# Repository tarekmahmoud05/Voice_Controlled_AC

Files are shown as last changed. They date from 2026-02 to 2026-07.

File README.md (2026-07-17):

# 🚗 Voice-Controlled Automotive Cabin Air Management System

An embedded systems project that automates rear-cabin climate control in vehicles, using dual temperature sensing, PWM-driven fan/hood logic, a custom motor driver shield PCB, and a Python voice-recognition interface for hands-free operation.

Built as part of the **Embedded Systems** and **Manufacturing of Electronic Components** modules — Electrical and Electronics Engineering, Coventry University.

---

## 📌 Table of Contents

- [Overview](#-overview)
- [Problem Statement](#-problem-statement)
- [System Architecture](#-system-architecture)
- [Hardware](#-hardware)
- [Control Logic](#-control-logic)
- [Voice Recognition Interface](#-voice-recognition-interface)
- [Repository Structure](#-repository-structure)
- [Getting Started](#-getting-started)
- [Testing](#-testing)
- [Results](#-results)
- [Future Work](#-future-work)
- [Team](#-team)
- [References](#-references)

---

## 🔍 Overview

Solar radiation through the rear windshield creates a "greenhouse effect" that conventional front-vent HVAC systems can't reach, with rear-cabin temperatures documented to exceed ambient by up to 47°C under direct sun. This forces manual driver adjustments mid-drive — a known distraction risk — and increases compressor load, raising fuel consumption by roughly 8%.

This project tackles that with a **roof-mounted ventilation system** built around an **AVR ATmega328P**, which autonomously switches between **intake (Fan Mode)** and **exhaust (Hood Mode)** based on real-time temperature deltas between the cabin and the outside air. A voice-controlled desktop app lets the driver set a target temperature hands-free, and a custom-fabricated PCB drives the motor.

## ❗ Problem Statement

- Rear cabin glazing causes thermal stratification untouched by standard HVAC vents
- Manual rear-climate adjustment while driving is a documented distraction hazard
- Compensating compressor load increases fuel consumption

## 🏗️ System Architecture

System Architecture Diagram

The firmware is organized into modular driver layers (ADC, DIO, PWM, UART, LCD, Button, String utilities), each with its own `.ino`/`.h` pair, integrated in a top-level main file. Full module breakdown, pin mapping, and control-flow diagrams are in [Project Design/CW3_project_design.md](Project%20Design/CW3%20project%20design.md)

## 🔧 Hardware

| Component | Function |
|---|---|
| ATmega328P (AVR) | Processes control logic, ADC inputs, and PWM output for the fan |
| Dual LM35 Temperature Sensors | Monitor cabin (`inTemp`) and ambient (`outTemp`) temperature |
| DC Fan | Roof-mounted intake/exhaust airflow |
| 16x2 LCD Display | Real-time temperature and system status |
| Push Button | Manual Start/Stop toggle and target-temperature trigger |
| L293D IC | Dual H-Bridge for bidirectional motor control |
| L7805 CV | 5V voltage regulator for stable logic power |
| Custom Motor Driver Shield (PCB) | In-house designed, milled, and soldered 2-layer shield carrying the L293D |
| Resistors/Capacitors | UART pull-ups and decoupling |

### Custom Motor Driver Shield (PCB)

Designed and fabricated as part of the Manufacturing of Electronic Components module:

1. **Circuit Design** — Schematic design of the motor driver shield
2. **Layout Design** — 2-layer PCB layout in Altium
3. **File Conversion** — G-code generation from Altium Gerber data
4. **Surface Mapping** — Auto-leveling the FR4 board for uniform milling depth
5. **Isolation Routing** — CNC milling of copper boundaries with a V-bit
6. **Drilling** — CNC drilling for through-hole component leads
7. **Post-Processing** — Deburring, cleaning, solder mask application
8. **Soldering** — Manual soldering with multi-point continuity validation

PCB schematics, layout files, and Gerber/G-code outputs are in [`pcb/`](pcb).

## 🧠 Control Logic

**Pin Mapping**

| Component | Pin | Type | Function |
|---|---|---|---|
| Internal Temp Sensor | PC5 | Analog In | Cabin temperature (`inTemp`) |
| External Temp Sensor | PC0 | Analog In | Ambient temperature (`outTemp`) |
| Control Button | PB4 | Digital In | Start/Stop toggle, triggers UART command |
| Motor Direction 1 | PD2 | Digital Out | Direction control (w/ PD3) |
| Motor Direction 2 | PD3 | Digital Out | Direction control (w/ PD2) |
| Motor Speed (PWM) | PB2 (OC1B) | PWM Out | Duty cycle 0–255 |
| LCD Data (D4–D7) | PD4–PD7 | Digital Out | 4-bit LCD data bus |
| LCD Enable | PB1 | Digital Out | LCD enable signal |
| LCD Register Select | PB0 | Digital Out | LCD command/data select |

**Fan/Hood decision logic:**
Fan Hood Decision Logic

Speed is mapped from the temperature difference onto an 8-bit PWM duty cycle (165–255 range, set by Timer 1 in Fast PWM Mode 14), generated via `OCR1B`. Direction is set through PD2/PD3, and motor commands are wrapped in `fan()`, `hood()`, and `stop()` helper functions on top of low-level `DC_Start`/`DC_Stop` calls.

Full firmware control flow, initialization routines, and the UART status-string framing are documented in [Project Design/CW3_project_design.md](Project%20Design/CW3%20project%20design.md)

## 🎙️ Voice Recognition Interface

A Python desktop application provides hands-free target-temperature control:

1. **Audio Capture** — PyAudio with ambient noise filtering
2. **Speech Processing** — Speech-to-text via the Google Speech Recognition API
3. **Command Parsing** — Keyword filtering to extract the numeric setpoint
4. **UART Bridge** — Sends the validated value to the ATmega328P at 9600 bps
5. **GUI Feedback** — Real-time system status and target temperature via TTKBootstrap

**Workflow:** press the button to start recording → speak the desired temperature → press the button again to stop recording and send it to the MCU.

## 📁 Repository Structure

Repository Structure Tree

## 🚀 Getting Started

### Hardware Requirements
- Arduino UNO / ATmega328P
- Dual LM35 temperature sensors
- L293D motor driver IC (on the custom shield, or a breakout)
- DC fan
- 16x2 LCD (4-bit mode)
- Push button
- L7805 voltage regulator
- USB cable for UART/serial connection

### Firmware Setup
1. Open `firmware/voice_Controlled_AC.ino` in the Arduino IDE
2. Connect components according to the [pin mapping](#-control-logic) above
3. Select board: **Arduino UNO**
4. Upload the sketch

## ✅ Testing

The `tests/` directory contains automated and semi-automated Python test scripts used to validate:
- ADC temperature readings against known reference values
- Serial communication / UART protocol framing
- Fan/Hood decision logic across the cabin/ambient temperature matrix
- Voice command parsing accuracy

Demonstration videos of the full system in operation are available in same directory.

## 📊 Results

Experimental testing showed the system reliably reduces thermal stagnation in the rear cabin and switches correctly between intake and exhaust modes according to the temperature differential logic, while the voice interface reduced the need for manual driver interaction with the climate controls.

## 🔮 Future Work

- **Sensor Fusion** — Add humidity and CO₂ sensors for air quality management and glass defogging, beyond just temperature
- **Wireless Connectivity** — Replace wired UART with Bluetooth/Wi-Fi for a fully wireless smartphone/PC-to-vehicle link
- **ML-Based Optimization** — Lightweight model to predict user temperature preferences from historical data and outdoor weather conditions

## Mady by

**Eng** Tarek Mahmoud Younes,
Student at **Coventry University**,
Specialized in **Electrical and Electronics Engineering**

**Supervised by:** Dr. Mostafa Rabie, Eng. Medhat Toubar
**School of Engineering — Electrical and Electronics Engineering, Coventry University**

## 📚 References

1. Alkhalaf, A., et al. (2021). *Investigation of the Effect of Solar Ventilation on the Cabin Temperature of Vehicles Parked under the Sun.* [mdpi.com](https://www.mdpi.com/2071-1050/13/24/13963)
2. Farrington, R. & Rugh, J. (2000). *Impact of vehicle air-conditioning on fuel economy.* [nrl.gov](https://docs.nlr.gov/docs/fy00osti/28960.pdf)
3. NHTSA (2021). *Driver distraction and in-vehicle climate controls.* [crashstats.nhtsa.dot.gov](https://crashstats.nhtsa.dot.gov/Api/Public/ViewPublication/813064)

---

*If you use or build on this project, a star ⭐ on the repo is always appreciated.*

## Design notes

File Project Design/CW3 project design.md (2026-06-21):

# Detailed Design Document

| **Author** | `Nour Eldien, Tarek Mahmoud Younes, Kareem Magdy` |
|:---|:---|
| **Status** | `Draft` |
| **Version** | `1.0.0` |
| **Date** | `8/12/2025` |

## Introduction

This document details the low-level design for the Automotive Cabin Air Management System firmware, an embedded system component built on an AVR microcontroller (arduino UNO). The system's primary function is to actively regulate the air temperature and flow within a vehicle cabin by controlling a DC Motor (used for fan or hood operation).  

The system continuously reads internal (In) and external (Out) temperatures via Analog-to-Digital Converter (ADC) channels and implements a Control Logic to automatically adjust the speed and direction (Forward/Backward/Stop) of the motor to match a target temperature.  

The human-machine interface involves:  

An LCD for continuous display of the system state, target temperature, and current In/Out temperatures.  

A Push Button for toggling the system's operational state (Start/Stop).  

A UART interface which links the embedded system to a desktop application. This interface is used to send operational state and to receive a dynamically set target temperature from the desktop application after a button press.  

### Purpose
The purpose of this detailed document is to define the implementation strategy, internal architecture, and public interfaces for the Automotive Cabin Air Management System firmware. This definition is critical for guiding the development process, ensuring:  

Accurate temperature measurement from both internal and external sensors.  

Reliable speed control of the DC motor via Pulse Width Modulation (PWM) in two directions.  

Effective Control Logic to maintain the target temperature.  

Robust UART communication to synchronize the system's state with the external desktop application, specifically enabling the dynamic setting of the target temperature upon a Stop command.  

### Scope
This document exclusively scopes the Software Design of the Automotive Cabin Air Management System firmware. It provides detailed specifications for the logic, data structures, and implementation of the following internal components:  

ADC Driver Logic: Handling the setup and reading of analog temperature sensor data from the defined In (internal) and Out (external) channels and applying the necessary calculations used for sensor calibration which is applied by multiplying the sensor reading fuction by the actual reading over the sensor reading itself.  

DC Motor and PWM Control: The logic for initializing the motor control pins, setting the DC motor's direction (Forward/Fan or Backward/Hood), and dynamically adjusting its rotational speed using Timer 1's 8-bit Fast PWM (0-255) output.  

Control Logic: The core decision-making mechanism that calculates the temperature difference to determine the required motor state, speed, and direction (an example can be seen in using the map function to scale the difference to a PWM duty cycle).  

UART Communication Protocol: The specific framing, parsing, and transmission logic for:  

    1/ Sending a message indicating the change in system state (Start/Stop) when the button is pressed.  

    2/ Receiving and parsing the new target temperature string (like  "25") from the desktop application.  

    3/ Transmitting the 15-byte status string containing the current motor state, target, internal, external temperatures, and motor speed for external monitoring.  

    4/ User Input and State Management: The handling of the debounced push button to toggle the system's operational state and trigger the appropriate UART messages and system functions.  

    5/ LCD Driver: The 4-bit mode logic for displaying current system parameters.  

## Architectural Overview
Architectural Overview Diagram

### Assumptions & Constraints
Assumptions and Constraints Diagram

## Functional Description

### Inputs/Outputs
|Component|	Pin|	Type|	Function|
|:---|:---|:---|:---|
|Internal Temp Sensor(In)|	PC5| Analog Input| Reads the temperature inside the vehicle cabin (inTemp).|
|External Temp Sensor(Out)|PC0 |Analog Input| Reads the temperature outside the vehicle cabin (outTemp).|
|Control Button|PB4 |Digital Input|Toggles the system's operational state (Start/Stop) and triggers UART commands.|
|DC Motor Direction 1| PD2|	Digital Output|	Controls motor direction (in conjunction with PD3).|
|DC Motor Direction 2| PD3 |Digital Output|	Controls motor direction (in conjunction with PD2).|
|DC Motor Speed (PWM)| PB2 | PWM Output| Controls the motor's rotational speed (Duty Cycle 0-255).|
|LCD Data Pins (D4:D7)| PD4:PD7| Digital Output| Transfers 4-bit data to the LCD module.|
|LCD Enable Pin (EN)| PB1| Digital Output| Toggles the Enable signal for LCD data transfer.|
|LCD Register Select (RS)| PB0|	Digital Output|	Selects between command and data registers on the LCD.|

### Functionlity

1. Temperature Acquisition and Display 

    The system continuously reads the analog raw values from ADC Channel 5 (inTempPin) and ADC Channel 0 (outTempPin), converts them to their corresponding temperature values, and stores them in inTemp and outTemp variables.  

    The current Target Temperature, Internal Temperature, and External Temperature are continuously displayed on the LCD.  

2. System State Management and Communication  
    The system maintains an operational state (state variable, toggled between 0 and 1).  

    When the Control Button is pressed and released:  

    The system state is toggled.  

    A corresponding UART command (Start or Stop) is sent to the external desktop application to synchronize the state.  

    Upon receiving the Stop command transmission, the system then expects a UART input string from the desktop application, which contains the new Target Temperature. This string is parsed and set as the new targetTemp.  

3. Control Logic  
    The firmware implements a closed-loop control mechanism to regulate the cabin temperature:  

    The difference is calculated as the absolute value of |inTemp - targetTemp|.  

    A deadband is enforced: If difference is less than or equal to 2, the motor is stopped (stop()).  

    If difference is greater than 2, the motor speed is calculated by mapping the difference to a PWM duty cycle (mapping a difference of 0-20 to a speed of 165-255).  

    Motor Direction Logic:  

        If inTemp > targetTemp (Cabin is too hot):  

            If outTemp < inTemp (Outside air is cooler), the motor runs in Fan/Forward mode (fan(speed)).  

            Otherwise, the motor runs in Hood/Backward mode (hood(speed)).  

        If inTemp < targetTemp (Cabin is too cold):  

            If outTemp > inTemp (Outside air is warmer), the motor runs in Fan/Forward mode (fan(speed)).  

            Otherwise (outside is colder or equal), the motor is stopped (stop()).  

4. Motor Output Control  
    The determined motor direction (CW/CCW) is set via the PD2/PD3 pins(motor pins).  

    The calculated speed is written to the Timer 1 Output Compare Register (OCR1B) to control the DC motor's speed using PWM on Pin 10(PB2).  

5. Status Feedback  
    The system periodically compiles a 15-byte status string containing the motor state (F/B/S), target temperature, internal temperature, external temperature, and motor speed.  

    This status string is transmitted over UART to the desktop application for continuous monitoring and logging.  

## Implementation of the Module
After Hardware Communication:  

#### Software

###### A. Initialization Routines (Startup)  
These steps are executed once upon system power-on or reset to configure the MCU peripherals and external components for operation.  

1/UART Initialization: Configures the serial interface for communication with the external desktop application.  

    Set baud rate to 9600 bps.  

    Enable the hardware Transmitter (TX) and Receiver (RX).  

2/LCD Initialization: Sets up the output communication for the display module.  

    Set the LCD data pins (PD4:PD7) and control pins RS (PB0) and EN (PB1) as outputs.  

    Apply a 20 ms power-on delay before sending commands.  

    Send the necessary commands for 4-bit initialization.  

    Configure the display: display is ON, cursor is OFF, entry mode sets cursor to be incremented, and the screen is cleared.  

3/Button Initialization: Configures the single control button input pin.  

    Initialize the Button structure (btnSetTemp).  

    Set the associated pin (PB4) as a digital input.  

    Disable the internal pull-up resistor (as it is assumed to be connected in a pulldown configuration).  

4/ADC Initialization: Configures the Analog-to-Digital Converter for temperature reading.  

    Set the reference voltage to AVcc pin.  

    Enable the ADC and apply a prescaler of 128 to the ADC clock source to achieve an appropriate clock speed (125 kHz).  

5/PWM Initialization: Configures Timer 1 for DC Motor speed control.  

    Set the PWM output pin (PB2/OC1B) as a digital output.  

    Configure Timer 1 to run in Fast PWM Mode 14 (TOP=ICR1).  

    Set the TOP value to 255 for 8-bit resolution.  

    Set the output to Non-Inverting Mode for OC1B.  

    Start Timer 1 with No Prescaler.  

    Initialize the duty cycle to 0 (Motor Off).  

6/DC Motor Initialization: Configures the direction control pins.  

    Set the motor direction pins (PD2 and PD3) as digital outputs.  

7/Initial Display Setup: Transmits required text strings to the LCD.  

    Display the persistent labels (e.g., "Target:", "In:", "Out:") on the LCD.  

###### B. Main Loop Logic (Continuous Operation)  
This loop runs indefinitely after initialization, handling core functionality:  

1/Temperature Reading:  

    Read the raw ADC value from Channel 0 (outTempPin) and convert it to outTemp.  

    Read the raw ADC value from Channel 5 (inTempPin) and convert it to inTemp.  

2/LCD Update and Motor Control Logic:  

    Convert inTemp, outTemp, and targetTemp integers into displayable strings.  

    Conditional LCD Clear: If the length of any of the temperature values changes (e.g., from 25 to 100), the LCD is cleared and the labels are re-written to prevent trailing digits.  

    Display all current temperature values (inTemp, outTemp, targetTemp) and the motor's state (Forward, Backward, or Stopped) on the LCD.  

    Calculate Error: Determine the absolute temperature difference: difference = abs(inTemp - targetTemp).  

    Motor Control (Proportional-like Logic):  

        If difference <= 2, call stop().  

        If difference > 2, calculate speed by mapping difference to the PWM range (e.g., 165 to 255).  

        Direction Logic: Determine whether to call fan(speed) (CW), hood(speed) (CCW), or stop() based on the comparison of inTemp vs. targetTemp and inTemp vs. outTemp.  

3/Control Button Handling:  

    Monitor the state of the debounced control button.  

    If the button state changes from Released to Pressed:  

        The system's operational state is toggled (0 to 1 or 1 to 0).  

        The corresponding state command (Start or Stop) is transmitted via UART to the desktop application.  

        If the new state is 'Stop' (0): The system waits for the desktop application to send the new target temperature via UART, which is then received, parsed using simple_atoi, and saved to targetTemp.  

4/Status Feedback Transmission:  

    The system assembles the 15-byte status string containing all relevant data (motorState, temperatures, speed).  

    The status string is transmitted via UART to the desktop application.  
### Notes
1/Default Pin Configuration: Any port pin is set by default to input when its corresponding DDRx bit is clear.  

2/Motor Function Mapping: The control functions fan(speed), hood(speed), and stop() are wrapper functions that handle the setting of the DC motor direction pins and the PWM duty cycle via DC_Start and DC_Stop.  

3/Target Temperature Update: The new target temperature is specifically received from the desktop application via UART after the control button is pressed to transition the system to the Stop state.  

4/Debouncing: The button input logic requires the button to be unpressed for a duration before a subsequent press can be registered, which is handled by the underlying Button library logic.  

5/Data Type Conversion: Custom functions like simple_atoi (ASCII to Integer) and int_to_string (Integer to ASCII) are used for data handling between the control variables and the UART/LCD interfaces.

### Static Files
The UCM module consists of the following arduino and header files:

| File name | Contents |
|---|---|
| Uart.ino | UART used-defined functions |
| Uart.h | The header file of the UART functions that includes declarations |
| Dio.ino | Input and output functions |
| Dio.h | The declaration file of digital input output funcitons |
| Adc.ino | The functions of Ananlog to Digital Conversion |
| Adc.h | The declaration ADC functions |
| Lcd.ino | The functions of LCD |
| Lcd.h | The declaration file of LCD functions |
| Pwm.ino | Functions to control the motor speed via PWM pins |
| Pwm.h | The declaration file PWM functions |
| DC_Motor.ino| Function for DC motor control|
| DC_Motor.h| The declaration file of DC motor contorl function|
| Button.ino | Button control functions |
| Button.h | The declaration file of button functions |
|myString.ino|  Custom string manipulation functions|
|myString.h| The declaration file of custom string funcitons
| voice_Controlled_AC.ino | Integrating all codes in one file according to the AC system function |

### Include Structure

Include Structure Diagram

### Configuration
The following parameters must be define according to the user case and situation.
| Name |Value range | Descriptio |
|---|---|---|
|F_CPU |16000000UL |The frequency of the MCU used for baud rate calculation |
|BaudRate | 9600 |The fixed baud rate for serial UART communication |
|Internal Temp ADC Channel |PC5|The Analog Channel used to read the Internal Cabin Temperature |
|External Temp ADC Channel |PC0  |The Analog Channel used to read the External Air Temperature |
|Control Button Pin  |  PB4 |The pin for the single Start/Stop Control Button that also triggers the target temperature update |
|DC Motor Direction Pin 1 | PB3 |One of the two pins controlling the DC Motor Direction |
|DC Motor Direction Pin 2| PD2 |The second pin controlling the DC Motor Direction  |
| LCD RS Pin  | PB0 | The Register Select (RS) pin for the LCD module.  |
|LCD Enable Pin | PB1 | The Enable (EN) pin for the LCD module. |
|LCD Data Port| PORTD (Pins 4-7)| he MCU port used for the 4-bit data transfer to the LCD| 
|Minimum Motor Speed (PWM)| 165 (out of 255)| The lowest acceptable PWM duty cycle when the motor is running to ensure effective air movement.|

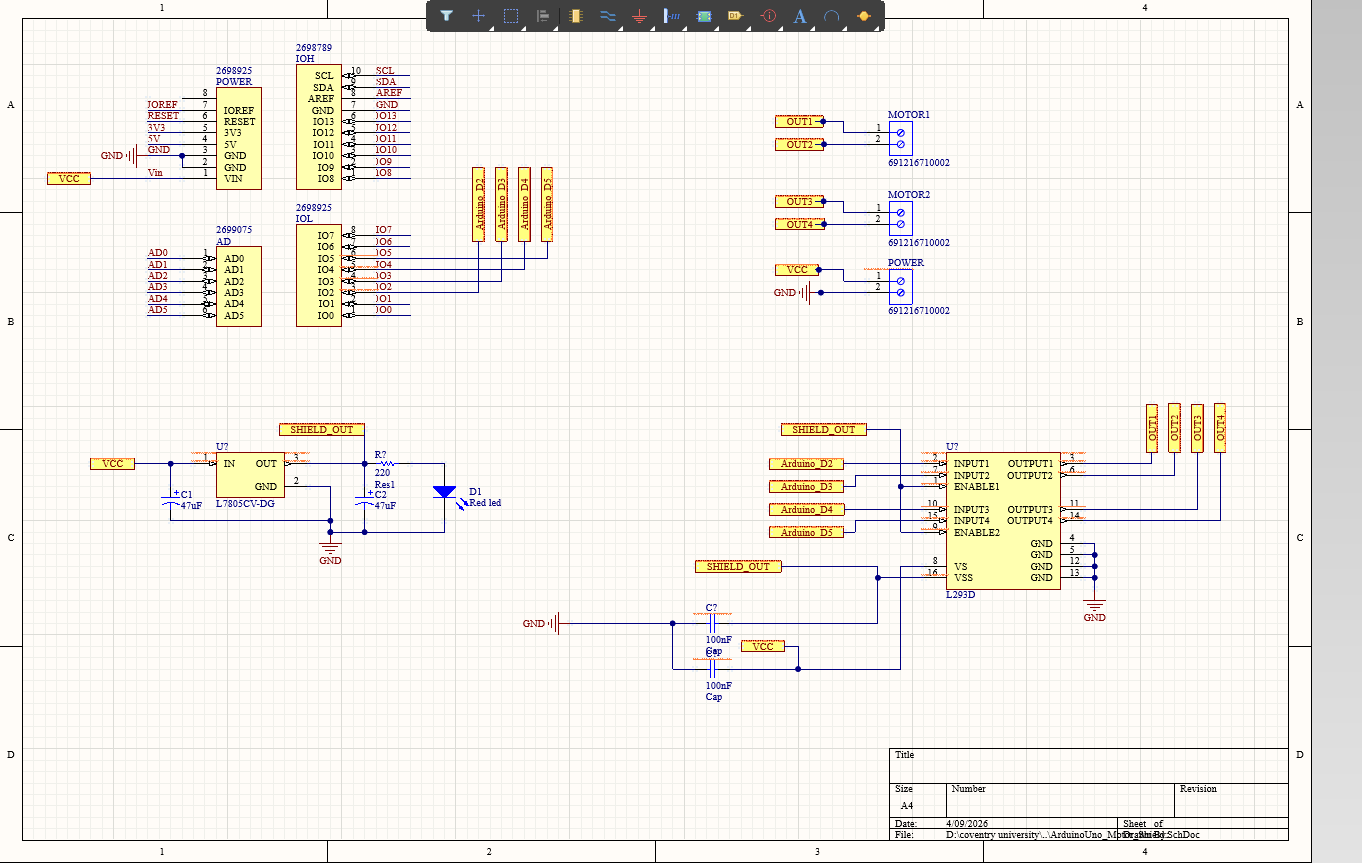
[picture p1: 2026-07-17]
pcb/sch.png

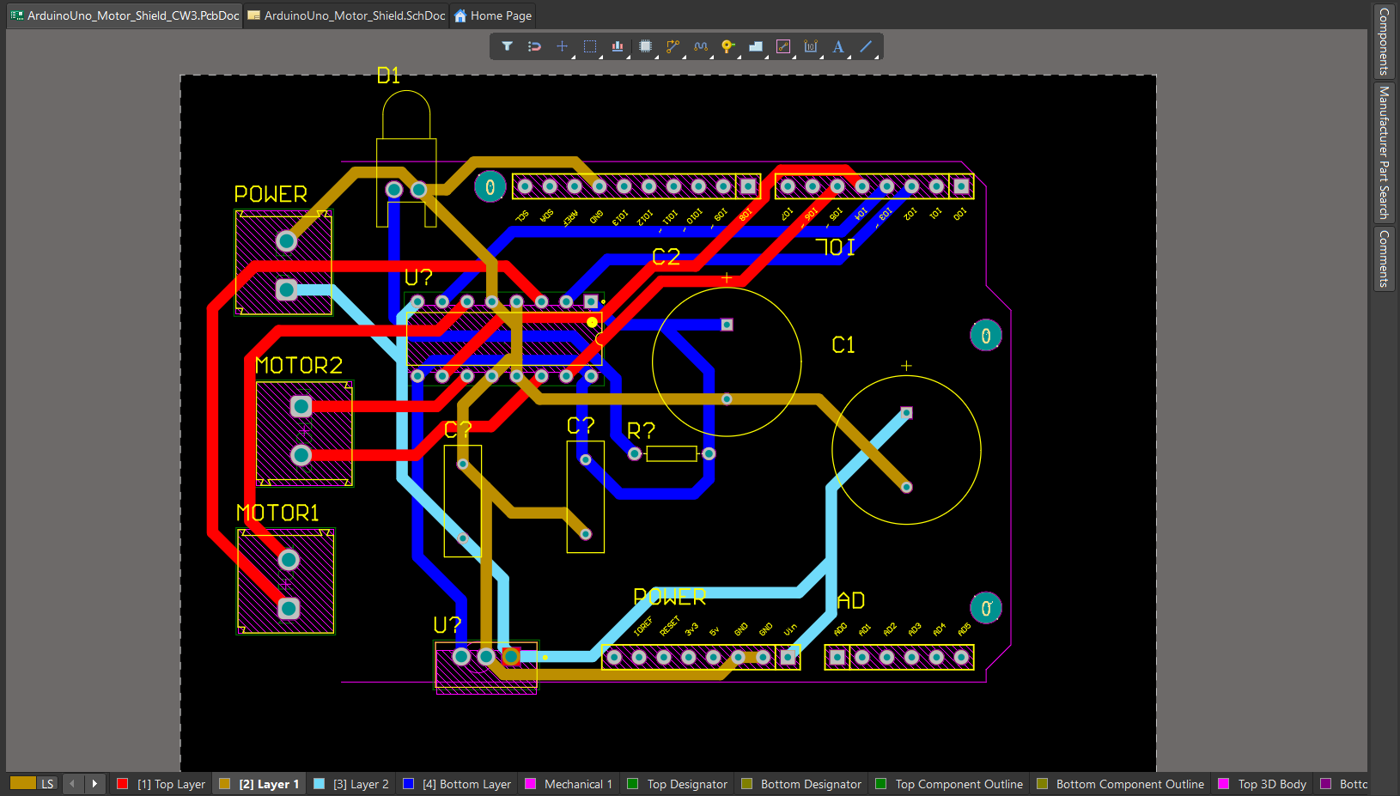
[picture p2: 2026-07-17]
pcb/four_layer.png

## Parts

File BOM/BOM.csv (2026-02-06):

Part | Description | Quantity | Manufacturer | Part Number | Datasheet | Price (EGP) | Total Price (EGP)
Arduino Uno | Arduino Uno Rev3 | 1 | Arduino | A000066 | https://docs.arduino.cc/resources/datasheets/A000066-datasheet.pdf | 420 | 420
Arduino Uno cable | usb type A to usb type B | 1 | Arduino |  |  | 30 | 30
holder 3 cells | 18650 battery holder | 1 |  |  |  | 22 | 22
Breadboard | 830 pin | 1 |  |  |  | 35 | 35
Push button | 4 pin | 1 |  |  |  | 0.75 | 0.75
Resistor | 220 ohm | 2 |  |  |  | 1.75 | 3.5
Jumper wires | male to male - male to female | 33 |  |  |  | 0.75 | 24.75
DC motor | 12 volt | 1 |  |  |  | 195 | 195
potintiometer | B1K | 1 |  |  |  | 5.5 | 5.5
LCD | 16 pin | 1 |  |  |  | 70 | 70
Motor driver | L298N | 1 |  |  |  | 75 | 75
Li-ion battery | rechargeable 18650 battery | 3 |  |  |  | 75 | 225
Temprature sensor | LM35 | 2 |  |  |  | 100 | 200
Propeller | 2 wings | 1 |  |  |  | 30 | 30
 |  |  |  |  |  |  | Total price
 |  |  |  |  |  |  | 1336.5

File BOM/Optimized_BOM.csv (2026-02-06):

Part | Description | Quantity | Manufacturer | Part Number | Datasheet | Price (EGP) | Total Price (EGP)
Microcontroller IC | ATmega328P-PU(DIP-28) | 1 | Atmel | ATmega328P | https://www.atmel.com/images/doc8161.pdf | 215 | 215
Decoupling Capacitor | 100nF | 1 |  |  |  | 1 | 1
Temperatue sensor | LM35 | 2 |  |  |  | 100 | 200
Resistor | 220 Ohm, 0.25W | 2 |  |  |  | 1.75 | 3.5
Push button | 4 pin | 1 |  |  |  | 0.75 | 0.75
Jumper Wires | Male-to-Male | 30 |  |  |  | 0.75 | 22.5
Crystal Oscillator | 16MHz | 1 |  |  |  | 5 | 5
Ceramic Capacitors | 22pF | 2 |  |  |  | 0.5 | 1
Pull-up Resistor | 10kohm | 1 |  |  |  | 0.2 | 0.2
Li-ion battery | rechargeable 18650 battery | 3 |  |  |  | 75 | 225
potintiometer | B1K | 1 |  |  |  | 5.5 | 5.5
LCD | 16 pin | 1 |  |  |  | 70 | 70
holder 3 cells | 18650 battery holder | 1 |  |  |  | 22 | 22
Motor driver | L298N | 1 |  |  |  | 75 | 75
DC motor | 12 volt | 1 |  |  |  | 195 | 195
Propeller | 2 wings | 1 |  |  |  | 30 | 30
Breadboard | 830 pin | 1 |  |  |  | 35 | 35
 |  |  |  |  |  |  | Total price
 |  |  |  |  |  |  | 1106.45

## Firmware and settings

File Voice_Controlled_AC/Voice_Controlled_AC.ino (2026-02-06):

#include "Adc.h"  // Analog-to-Digital Converter driver
#include "Dio.h"  // Digital Input/Output driver
#include "DC_Motor.h" // DC Motor control driver
#include "Lcd.h"  // LCD display driver
#include "myString.h" // Custom string manipulation functions (e.g., int_to_string, simple_atoi)
#include "Pwm.h"  // Pulse Width Modulation driver
#include "Button.h" // Button driver
#include "Uart.h" // Universal Asynchronous Receiver/Transmitter (Serial) driver
#include <stdint.h> // Standard integer types
#include <util/delay.h> // Header for _delay_ms function (added based on its usage)

#define outTempPin 0  // ADC Channel for the outdoor temperature sensor
#define inTempPin 5 // ADC Channel for the indoor temperature sensor
#define buttonPin 4 // Pin for the control button (PB4 based on init)
Button btnSetTemp;  // Structure/object to manage the control button state
char receivedTarget[3]="25";  // Buffer to store the 2-digit target temperature received via UART
int targetTemp=25;  // Integer version of the target temperature
int lastIn; // Stores the previous indoor temperature for LCD clear check
int lastOut;  // Stores the previous outdoor temperature for LCD clear check
int lastTarget; // Stores the previous target temperature for LCD clear check
char target[3]="25";  // String version of the target temperature for LCD display
int state = 0;  // System state: 0 (Off), 1 (Running)
char motorState; // Motor state indicator: 'B' (Backward/Hood), 'F' (Forward/Fan), 'S' (Stopped)

/**
 *Controls the DC Motor to act as a Hood (e.g., exhausting hot air).
 *speed The PWM duty cycle/speed (0-255).
 */
void hood(int speed){
  DC_Start(0, DIRECTION_CCW, speed);  // Start DC Motor 0 in Counter-Clockwise (CCW) direction
  LCD_String_xy(1,0,"Backward");  // Display motor direction on LCD
  motorState='B'; // Update motor state
}

/**
 *Controls the DC Motor to act as a Fan (e.g., pulling in cool air or circulating).
 *speed The PWM duty cycle/speed (0-255).
 */
void fan(int speed){
  DC_Start(0, DIRECTION_CW, speed); // Start DC Motor 0 in Clockwise (CW) direction
  LCD_String_xy(1,0,"Forward ");  // Display motor direction on LCD
  motorState='F'; // Update motor state
}

/**
 *Stops the DC Motor.
 */
void stop(){
  DC_Stop(0); // Stop DC Motor 0
  LCD_String_xy(1,0,"Stopped"); // Display motor state on LCD
  motorState='S'; // Update motor state
}

// --- Initialization Section ---
int main(){

  Uart_Init();  // Initialize UART communication
  LCD_Init(); // Initialize LCD display
  Button_init(&btnSetTemp, &DDRB, &PORTB, &PINB, PB4);  // Initialize button on PB4
  Adc_Init(); // Initialize ADC for temperature sensors
  PWM_Init(); // Initialize PWM for motor speed control
  DC_Init();  // Initialize DC Motor driver
  // Initial LCD display setup
  LCD_String_xy(0,0, "Target:");
  LCD_String_xy(0,10, "In:");
  LCD_String_xy(1,10, "Out:");

  // --- Main Control Loop ---
  while(1)
  {

    char difference;  // Stores the absolute difference between indoor and target temp
    int outTemp;  // Stores the calculated outdoor temperature
    int inTemp; // Stores the calculated indoor temperature
    char out[3];  // String buffer for outdoor temp (2 digits + null term)
    char in[3]; // String buffer for indoor temp
    char sp[4]; // String buffer for motor speed (3 digits + null term)
    char all[15]; // Combined string buffer for UART transmission

    // 1. Voice/UART Target Temperature Update
    if (Uart_IsDataAvailable())
    {
      Uart_ReadString(receivedTarget, 3); // Read up to 2 characters (plus null) from UART
      targetTemp=simple_atoi(receivedTarget); // Convert received string to integer target temperature
    }
    // 2. System State (Start/Stop) Control via Button
    if (btnSetTemp.getState(&btnSetTemp) == BTN_PRESSED && state == 0)  
    {
      Uart_SendString("Start\n",6); // Send "Start" confirmation via UART
      state = 1;  // Change state to Running
    }
    else if (btnSetTemp.getState(&btnSetTemp) == BTN_PRESSED && state == 1)
    {
      Uart_SendString("Stop\n",5);  // Change state to Running (Automatic)
      state = 0;  // Change state to Manual/Off
    }
    while(btnSetTemp.getState(&btnSetTemp) == BTN_PRESSED);// Debounce/wait for the button to be released.

    // 3. Read and Convert Temperatures
    // The formula (*19/44) is used to calibratre the temperature sensor
    inTemp = Adc_ReadChannel(inTempPin)*19/44;
    outTemp = Adc_ReadChannel(outTempPin)*19/44;

    // Convert integer temperatures to strings for LCD display
    int_to_string(inTemp,in);
    int_to_string(outTemp,out);
    int_to_string(targetTemp,target);

    // 4. LCD Clear Check
    // If any temperature/target number of digits changes (e.g., 9 -> 10 or 10 -> 9), clear LCD to prevent old digits from remaining.
    if (number_of_digits(inTemp)<number_of_digits(lastIn) || number_of_digits(outTemp)<number_of_digits(lastOut) || number_of_digits(targetTemp)<number_of_digits(lastTarget))
    {
      LCD_Clear();
      LCD_String_xy(0,0, "Target:");
      LCD_String_xy(0,10, "In:");
      LCD_String_xy(1,10, "Out:");
    }

    // 5. Display Current Temperatures and Target on LCD
    LCD_String_xy(0,7,target);  // Display Target Temp
    LCD_String_xy(0,13,in); // Display Indoor Temp
    LCD_String_xy(1,14,out);  // Display Target Temp
    //Uart_SendString(target,2);

    difference = abs(inTemp-targetTemp);  // Calculate absolute temperature error

    // Map the temperature difference (0-20) to a PWM speed (165-255).
    // min(..., 255) ensures speed does not exceed max PWM duty cycle.
    int speed = min(map(difference, 0, 20, 165, 255), 255);
    if(difference > 2){ // Only run motor if difference is greater than 2 degrees
      if(inTemp > targetTemp){  // Indoor temp is too high (needs cooling)
        if(outTemp < inTemp)  // If outdoor air is cooler than indoor air
          fan(speed); // Pull in cooler outdoor air (Fan)
        else
          hood(speed);  // Otherwise, exhaust indoor hot air (Hood)
      }
      else if(outTemp > inTemp) // If outdoor temp is warmer than indoor, pull it in.
        fan(speed);
      else{
        stop();
      }
    }
    else 
      stop(); 
// Convert speed integer to string (sp) by repeatedly taking modulo 10
    int cnt = 3;
    while(cnt--){
      sp[cnt] = speed%10 + '0';
      speed /= 10;
    }
// Construct the comma-separated data string (all)
// Format: MotorState,TargetTemp,InTemp,OutTemp,Speed\n (15 characters total)
  for (int i=0; i<(sizeof(all)/sizeof(all[0]))-1;i++)
  {
    if (i==0)
      all[0]=motorState;

    else if (i == 1 || i == 4 || i == 7 || i == 10)
      all[i]=',';

    else if(i <= 3)
      all[i]=receivedTarget[i-2];

    else if(i <= 6)
      all[i]=in[i-5];

    else if(i <= 9)
      all[i]=out[i-8];
    else
      all[i]=sp[i-11];
  }
  all[14] = '\n';
  Uart_SendString(all,15);  
// 8. Update Last Values and Delay
  lastIn=inTemp;
  lastOut=outTemp;
  lastTarget=targetTemp;
  _delay_ms(100);
  }

}
  

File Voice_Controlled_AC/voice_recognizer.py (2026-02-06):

import threading
import speech_recognition as sr
import pyaudio
import audioop
import ttkbootstrap as ttk
from ttkbootstrap.constants import *
from word2number import w2n
import re
import tkinter as tk
import serial
import math

COM_PORT = 6
BAUD_RATE = 9600

CHUNK = 1024
FORMAT = pyaudio.paInt16
CHANNELS = 1
RATE = 44100

def get_temp_color(temp):
    # Clamp temp between 0 and 50 for color calculation
    t = max(0, min(50, temp)) / 50.0
    
    # Cold (Blue) -> Comfortable (Greenish) -> Hot (Red)
    if t < 0.5:
        # Interpolate Blue to Green
        ratio = t * 2
        r = int(52 + (46 - 52) * ratio)
        g = int(152 + (204 - 152) * ratio)
        b = int(219 + (113 - 219) * ratio)
    else:
        # Interpolate Green to Red
        ratio = (t - 0.5) * 2
        r = int(46 + (231 - 46) * ratio)
        g = int(204 + (76 - 204) * ratio)
        b = int(113 + (60 - 113) * ratio)
        
    return f'#{r:02x}{g:02x}{b:02x}'

class WeatherCanvas(tk.Canvas):
    def __init__(self, master, width=100, height=100, **kwargs):
        super().__init__(master, width=width, height=height, highlightthickness=0, **kwargs)
        self.width = width
        self.height = height
        self.cx = width // 2
        self.cy = height // 2

    def draw_weather(self, temp):
        self.delete("all")
        if temp >= 30: 
            self._draw_sun()
        elif temp <= 15:
            self._draw_snow()
        else:
            self._draw_cloud()

    def _draw_sun(self):
        self.create_oval(self.cx-20, self.cy-20, self.cx+20, self.cy+20, fill="#f1c40f", outline="#f39c12", width=2)
        for i in range(0, 360, 45):
            rad = math.radians(i)
            x1 = self.cx + math.cos(rad) * 25
            y1 = self.cy + math.sin(rad) * 25
            x2 = self.cx + math.cos(rad) * 35
            y2 = self.cy + math.sin(rad) * 35
            self.create_line(x1, y1, x2, y2, fill="#f39c12", width=3)

    def _draw_snow(self):
        self.create_text(self.cx, self.cy, text="❄", font=("Arial", 60), fill="white")

    def _draw_cloud(self):
        self.create_oval(self.cx-30, self.cy-10, self.cx+10, self.cy+20, fill="#ecf0f1", outline="")
        self.create_oval(self.cx-10, self.cy-20, self.cx+30, self.cy+15, fill="#ecf0f1", outline="")

class FanWidget(tk.Canvas):
    def __init__(self, master, width=180, height=180, **kwargs):
        super().__init__(master, width=width, height=height, highlightthickness=0, **kwargs)
        self.cx = width // 2
        self.cy = height // 2
        self.angle = 0
        self.direction = 'S'
        self.speed = 0
        self.blade_color = "#95a5a6"
        self.draw_static_frame()
        self.animate()

    def draw_static_frame(self):
        self.create_oval(self.cx-80, self.cy-80, self.cx+80, self.cy+80, outline="#555", width=8)
        self.create_oval(self.cx-5, self.cy-5, self.cx+5, self.cy+5, fill="#333")

    def set_state(self, direction, speed):
        self.direction = direction
        self.speed = speed

    def animate(self):
        self.delete("blade")
        
        step = 0
        if self.direction == 'F': 
            step = (self.speed / 255.0) * 30 + 2
            self.blade_color = "#2ecc71" 
        elif self.direction == 'B':
            step = -((self.speed / 255.0) * 30 + 2)
            self.blade_color = "#e74c3c" 
        else:
            self.blade_color = "#95a5a6"

        self.angle = (self.angle + step) % 360

        for i in range(3):
            blade_angle = math.radians(self.angle + (i * 120))
            x_tip = self.cx + math.cos(blade_angle) * 70
            y_tip = self.cy + math.sin(blade_angle) * 70
            
            x_l = self.cx + math.cos(blade_angle - 0.3) * 20
            y_l = self.cy + math.sin(blade_angle - 0.3) * 20
            
            x_r = self.cx + math.cos(blade_angle + 0.3) * 20
            y_r = self.cy + math.sin(blade_angle + 0.3) * 20
            
            self.create_polygon(self.cx, self.cy, x_l, y_l, x_tip, y_tip, x_r, y_r, 
                              fill=self.blade_color, tags="blade", outline="black")
        
        self.after(50, self.animate)

class SmartHVACApp(ttk.Window):
    def __init__(self):
        super().__init__(themename="superhero")
        self.title("Smart HVAC Controller")
        self.geometry("1000x600")
        
        self.recognizer = sr.Recognizer()
        self.is_recording = False
        self.frames = []
        self.ser = None
        
        self.target_temp = 25
        self.inside_temp = 25
        self.outside_temp = 35 
        
        self.setup_ui()
        
        self.serial_thread = threading.Thread(target=self.listen_to_arduino, daemon=True)
        self.serial_thread.start()

    def setup_ui(self):
        self.container = tk.Frame(self)
        self.container.pack(fill=BOTH, expand=YES)
        
        self.left_pane = tk.Frame(self.container, bg="#3498db", width=400)
        self.left_pane.pack(side=LEFT, fill=BOTH, expand=YES)
        self.left_pane.pack_propagate(False)

        self.center_pane = tk.Frame(self.container, bg="#2c3e50", width=200)
        self.center_pane.pack(side=LEFT, fill=Y)
        self.center_pane.pack_propagate(False)

        self.right_pane = tk.Frame(self.container, bg="#e74c3c", width=400)
        self.right_pane.pack(side=LEFT, fill=BOTH, expand=YES)
        self.right_pane.pack_propagate(False)

        # --- LEFT PANE (OUTSIDE) ---
        tk.Label(self.left_pane, text="OUTSIDE", font=("Helvetica", 18, "bold"), bg=self.left_pane["bg"], fg="white").pack(pady=20)
        self.weather_icon_out = WeatherCanvas(self.left_pane, width=100, height=100, bg=self.left_pane["bg"])
        self.weather_icon_out.pack(pady=10)
        self.lbl_out_temp = tk.Label(self.left_pane, text="--°C", font=("Helvetica", 60, "bold"), bg=self.left_pane["bg"], fg="white")
        self.lbl_out_temp.pack(pady=20)
        self.lbl_out_status = tk.Label(self.left_pane, text="Status", font=("Helvetica", 14), bg=self.left_pane["bg"], fg="#ecf0f1")
        self.lbl_out_status.pack()

        # --- CENTER PANE (FAN & CONTROLS) ---
        tk.Label(self.center_pane, text="AIRFLOW", font=("Helvetica", 12, "bold"), bg="#2c3e50", fg="#bdc3c7").pack(pady=20)
        self.fan = FanWidget(self.center_pane, bg="#2c3e50")
        self.fan.pack(pady=10)
        
        self.lbl_fan_status = tk.Label(self.center_pane, text="IDLE", font=("Courier", 10, "bold"), bg="#2c3e50", fg="#f39c12")
        self.lbl_fan_status.pack(pady=5)

        self.mic_bar = ttk.Progressbar(self.center_pane, length=150, maximum=20000, bootstyle="info")
        self.mic_bar.pack(pady=30)
        
        self.btn_record = ttk.Button(self.center_pane, text="WAITING", bootstyle="secondary", state="disabled", width=15)
        self.btn_record.pack(pady=10)
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

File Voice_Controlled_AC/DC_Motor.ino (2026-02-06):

#include "DC_Motor.h"
#include "Pwm.h"
#include <util/delay.h>
#if !defined(__AVR_ATmega328P__)
#include <avr/iom328p.h>
#endif

// Define CPU Frequency (Crucial for _delay_ms to work correctly)
// Assuming a standard 16MHz Arduino/AVR clock speed.
#define F_CPU 16000000UL 

// Pin assignments for motor (MotorID 0: PD2 and PD3)
unsigned char MotorArray[][2] = {
    {2, 3} 
};

// --- PWM Functions (Timer 1, OC1B/PB2/Digital Pin 10) ---



// --- DC Motor Control Functions (Port D) ---

void DC_Init(){
    // Dynamically set all motor pins as output pins
    for (unsigned char i = 0; i < sizeof(MotorArray)/sizeof(MotorArray[0]); ++i) {
        DDRD |= (1 << MotorArray[i][0]);
        DDRD |= (1 << MotorArray[i][1]);
    }
}

void DC_Start(unsigned char MotorID, tenuDirection Direction, unsigned char Speed){

    if (Direction == DIRECTION_CW)
    {
        // Set Pin 1 HIGH and Pin 2 LOW for CW rotation
        PORTD |= (1 << MotorArray[MotorID][0]);
        PORTD &= ~(1 << MotorArray[MotorID][1]);
    } else{
        // Set Pin 1 LOW and Pin 2 HIGH for CCW rotation
        PORTD &= ~(1 << MotorArray[MotorID][0]);
        PORTD |= (1 << MotorArray[MotorID][1]);
    }
    
    // Apply the PWM speed to the motor's Enable pin (via OCR1B/PB2)
    Pwm_SetDutyCycle(Speed);

}

void DC_Stop(unsigned char MotorID){
    // Active Brake: Sets both pins HIGH, shorting the motor leads to VCC/Ground
    PORTD |= (1 << MotorArray[MotorID][0]);
    PORTD |= (1 << MotorArray[MotorID][1]);
    
    // Also stop the PWM signal
    Pwm_SetDutyCycle(0);
}
